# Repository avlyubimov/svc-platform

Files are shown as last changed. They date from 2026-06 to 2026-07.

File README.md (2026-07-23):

# SVC Platform — Smart Vehicle Controller

<p align="center">
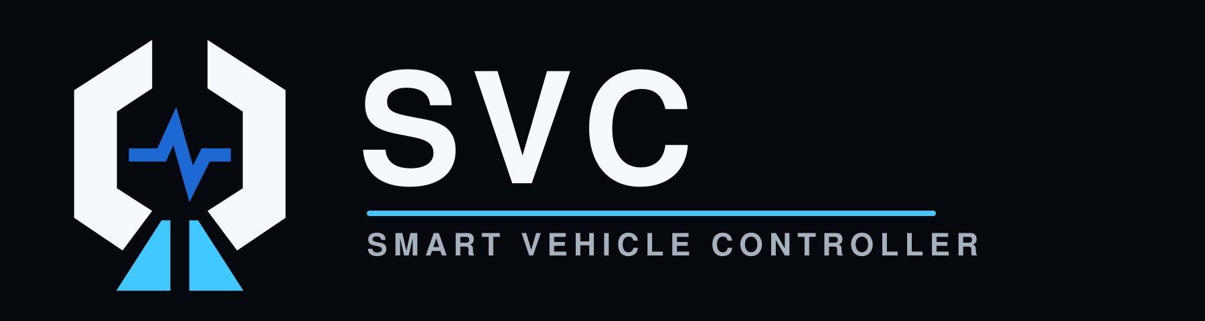
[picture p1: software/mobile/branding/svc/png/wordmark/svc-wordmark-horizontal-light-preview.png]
SVC — Smart Vehicle Controller
  
</p>

<p align="center">
  Open modular hardware, firmware, and mobile software for controlling
  auxiliary equipment on motorcycles and other vehicles.
</p>

**Reference Vehicle #001:** BMW R1200GS K25 2007<br>
**VIN:** WB10307A97ZU65028

## Mission

SVC should allow new functionality to be added primarily through configuration,
plugins, firmware updates, or Logic Board replacement without redesigning the
Power Board.

## Current status

Architecture v1.0 is frozen. Firmware safety, configuration, role mapping,
rule execution, CAN safety, update policy, and PWM ownership have host-tested
scaffolds.

The three boards are moving through the controlled EVT lifecycle independently:

| Board | Current repository state | Release boundary |
| --- | --- | --- |
| **PB-100** | `EVT-LAYOUT-AUTHORIZED` | Partial layout only; fabrication and production remain blocked |
| **LB-100** | `EVT-FAB-AUTHORIZED` | One segregated five-piece bare-PCB EVT package only |
| **FB-100** | `EVT-LAYOUT-AUTHORIZED` | Layout may continue; fabrication and production remain blocked |

These states describe the current `master` baseline. They do not authorize a
combined board order or production release. Detailed and machine-checked gates
are tracked in
[`docs/product/final-readiness.md`](docs/product/final-readiness.md).

## Mobile application

<p align="center">
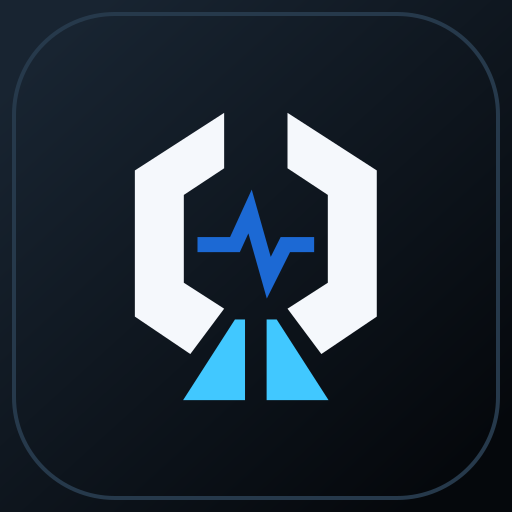
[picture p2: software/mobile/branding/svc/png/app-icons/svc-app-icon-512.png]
SVC mobile application icon
  
  &nbsp;&nbsp;&nbsp;&nbsp;
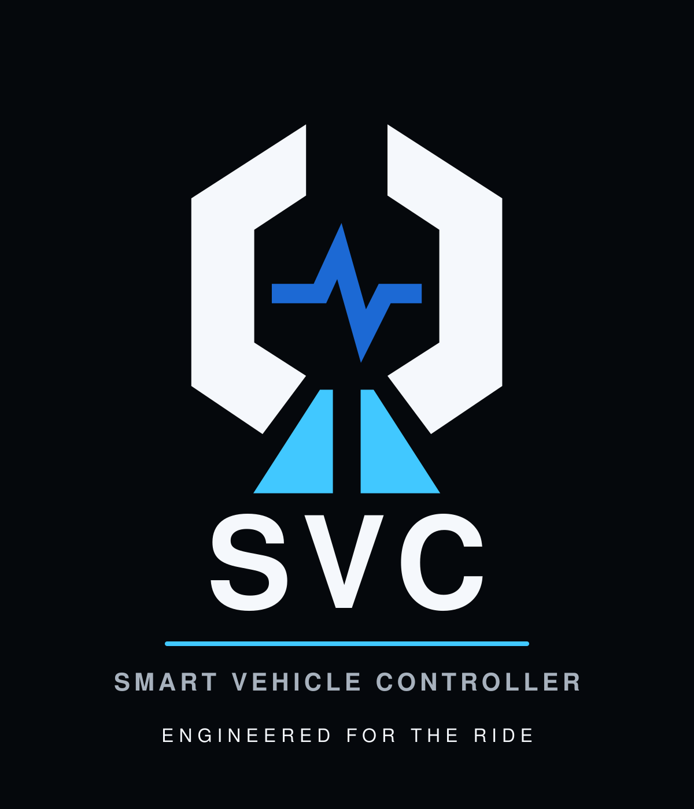
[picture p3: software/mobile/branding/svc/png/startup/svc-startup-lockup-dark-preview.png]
SVC mobile startup identity
  
</p>

SVC Mobile is being developed for iOS and Android. It provides the foundation
for live telemetry, diagnostics, vehicle data, channel control, event history,
configuration, and phone-mediated firmware updates. CHIGEE AIO-6 is treated as
a CarPlay/Android Auto projection host; the applications run on the phone.

The committed mobile baseline includes SwiftUI and Jetpack Compose
applications, BLE and protocol layers, mock data, projection scaffolds, a
GitHub Releases client, and signed-update validation. Physical channel control,
live BLE integration, and firmware transfer/installation remain disabled or
mock-backed until hardware validation closes the applicable safety gates.

The images above use only the project-owned SVC identity.
Vehicle-manufacturer artwork is not part of this repository presentation.

### SVC Ride Dashboard

<p align="center">
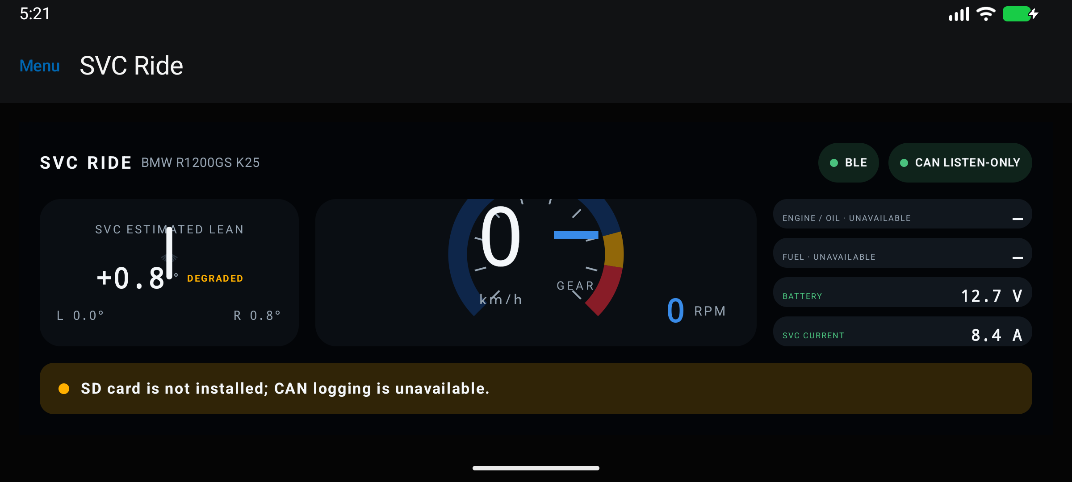
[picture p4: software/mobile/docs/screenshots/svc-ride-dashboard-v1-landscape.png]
SVC Ride Dashboard v1 with mock telemetry and SVC-only visual identity
  
</p>

Dashboard v1 is implemented for the SwiftUI and Jetpack Compose phone targets.
It uses separate versioned vehicle-performance profiles, explicit telemetry
quality states, profile-driven tachometer zones, SVC-estimated lean, Day/Night
themes, Reduce Motion, and adaptive landscape/portrait layouts. Missing CAN
signals remain `—`; gear is not inferred from speed and RPM. CarPlay and
Android Auto retain a separate, reduced information-only template.

- [Mobile overview and local build commands](software/mobile/README.md)
- [iOS application](software/mobile/ios/SVCMobile/README.md)
- [Android application](software/mobile/android/README.md)
- [Firmware update trust boundary](docs/architecture/firmware-update.md)
- [SVC identity assets](software/mobile/branding/svc/README.md)
- [Ride Dashboard implementation boundary](software/mobile/docs/ride-dashboard-roadmap.md)

## Validation

```bash
make check
```

This runs repository readiness checks, KiCad validation, firmware configuration
validation and host tests, mobile protocol tests, and release-policy checks.
The same command runs in GitHub Actions on push and pull request.

Platform-specific mobile workflows additionally build and test the Android and
iOS projects in GitHub Actions.

## Repository structure

```text
docs/                 Architecture, ADR, requirements, production docs
hardware/             KiCad and mechanical files
firmware/             Embedded firmware, bootloader, plugins
software/             SVC Studio and SVC Mobile
can-db/               Vehicle CAN databases
production/           BOM, Gerber, Pick&Place, assembly docs
tools/                Readiness, protocol, security, and release validation
```

## Board naming

- **PB-100** — Power Board, intended to remain stable for 10–15 years.
- **LB-100** — Logic Board, replaceable and upgradeable.
- **FB-100** — Front Panel Board, service interface and indicators.

## Hard rule

**Power Board is sacred.**

New features should not require Power Board redesign unless all configuration,
plugin, firmware, and Logic Board options are exhausted.

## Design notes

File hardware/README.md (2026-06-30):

# Hardware

## Boards

- PB-100 Power Board
- LB-100 Logic Board
- FB-100 Front Panel Board

Do not create KiCad layout until architecture is frozen.

Architecture v1.0 is frozen. PB-100 schematic planning may proceed, but PCB
layout remains blocked until schematic inputs are reviewed.

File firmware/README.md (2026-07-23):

# Firmware

Target architecture:
- FreeRTOS
- drivers
- event bus
- services
- plugins
- rule engine
- logger
- BLE/USB API

Update scaffolds:

- `radio/e73/` — Zephyr/nRF52840, MCUboot, MCUmgr/SMP over BLE, UART bridge,
  SWD recovery instructions.
- `bootloader/stm32h5/` — host-buildable OEMiRoT integration boundary for
  STM32H563; it is not an ad-hoc production bootloader.
- `update/` — target-neutral chunk/resume/admission/trial-boot state machine and
  the E73-to-STM32 UART framing contract.

No direct feature-to-hardware coupling. Use Output Manager and role mapping.

## Host validation

Run from `firmware/`:

```bash
make test
```

The firmware Makefile treats `core/*.h` and `services/*.h` as host-test
prerequisites, so interface changes force test binary rebuilds.

Current host tests cover:

- Configuration validation for battery settings, power budget, and output role
  enum bounds without role-to-output assumptions.
- Configuration Store record validation and two-slot selection so firmware
  defaults do not overwrite valid persisted user configuration.
- Configuration Store wrap-aware sequence selection across two persisted slots.
- Configuration Store reserved-field validation before accepting persisted
  records.
- Configuration Update preparation that refuses to persist a config until it is
  accepted against hardware capability.
- Configuration acceptance for a discovered hardware capability contract before
  startup uses a configuration.
- Hardware capability validation that checks generic board limits, safe defaults,
  CAN1 read-only policy, and config electrical limits without role assumptions.
  PB-100's compiled capability constant is checked against the JSON hardware
  capability manifest by repository validation.
- PB-100 board-level power budget service and configured load-shed ordering.
- Output Manager safe default-off, enable/disable, budget denial, telemetry
  denial, priority shedding, PWM increase revalidation, thermal derating, and
  fault lockout behavior.
- Overflow-safe projected-current denial for output starts and PWM increases.
- Battery protection warning, overflow-safe delayed cutoff latch using
  `shutdown_delay_s`, recovery, and invalid telemetry behavior.
- Event Bus FIFO order, overflow rejection, and empty-pop behavior.
- Event Dispatcher output overcurrent/fault handling through Output Manager.
- Event Log fixed-size diagnostic ring buffer with overwrite/drop accounting
  that saturates instead of wrapping the diagnostic drop counter.
- CAN1 listen-only TX denial and CAN2 expansion TX allowance.
- CAN RX Log fixed-size receive-only diagnostics plus a separate ISR-to-logger
  CAN1 queue, 44-byte v2 CRC records with 64-bit microsecond timestamps,
  identity-bearing 128-byte FatFs session headers, independent sync/close,
  restart/reopen, preallocation, rotation and torn-tail recovery. The target
  STM32 disk-I/O binding remains required before motorcycle logging tests.
- CAN Event Decode from received frames to internal Event Bus state-change
  events without output control.
- CAN Event Decode dropped-edge retry behavior when the Event Bus is full.
- Rule Event Bridge that drains CAN-derived and other condition events into rule
  condition state while retaining non-rule events for safety dispatch.
- Rule Runtime step that runs bridge, fault dispatch, and ordered rule
  evaluation in a safety-preserving order.
- System Safety Coordinator integration between battery cutoff, power-budget
  shedding, thermal derating/cutoff, Event Bus, and Output Manager output
  shutdown.
- System Safety runtime fail-safe shutdown when total-current telemetry is stale
  or invalid.
- System Safety retry of dropped runtime power-budget shed events.
- Role Resolver and Rule Engine role-action runner through Output Manager.
- Rule condition state tracking for engine, high-beam, left-indicator, and
  ambient-light day/dusk/night events.
- Rule runner evaluation for matched/unmatched conditions before role actions.
- Rule set runner for ordered multi-rule evaluation, skipped-rule accounting,
  and stop-on-first-failure behavior.
- Rule text parser for the initial supported JSON rule condition/action grammar.
- Output Manager PWM duty-cycle ownership and `pwm_allowed` enforcement.
- Rule text compile helpers from condition/action strings to in-memory
  `svc_rule_t` and ordered `svc_rule_t` arrays for multi-action rules.
- Rule-set compilation rejects invalid multi-action rule text before writing
  compiled rule entries or caller-provided condition buffers.
- Rule action grammar alignment between the JSON Schema, repository
  configuration validator, and firmware parser for supported roles and PWM
  values, with canonical `0` or `1..100` PWM literals.
- Runtime Boot path from direct configuration or persistent store that keeps
  outputs off unless configuration and hardware capability checks pass.
- Runtime Boot invalid-argument handling that leaves runtime state safe/off.
- Telemetry Snapshot validity/staleness for battery, total current, and
  per-output current samples.
- Telemetry-backed System Safety and Rule Engine wrappers for stale-data fail
  safe behavior.
- Thermal Protection allow/derate/cutoff decisions for PB-100 thermal zones.
- Thermal System Safety derating through Output Manager at warning threshold and
  shutdown through Output Manager on cutoff/stale telemetry.
- Firmware-update protocol mismatch, hardware mismatch, corrupt/repeated chunks,
  interruption/resume, incomplete file, hash/signature denial, parked-state
  admission, power loss before confirmation, rollback, and E73/STM32 version
  compatibility.

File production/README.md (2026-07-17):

# Production

This folder contains production artifacts:

- BOM drafts in `production/bom/factory_bom_draft.csv` and
  `production/bom/garage_bom_draft.csv`.
- Symbol-to-BOM ownership in `production/bom/pb100_symbol_bom_map.csv`.
- Assembly sourcing recheck tracking in
  `production/bom/pb100_assembly_sourcing_recheck.csv`.
- Current sourcing evidence snapshots in
  `production/bom/pb100_sourcing_evidence_snapshot.csv`.
- Future Gerber, Pick&Place, assembly notes, and JLCPCB/PCBWay settings after
  schematic freeze and layout authorization.

Use `make pb100-release-status` from the repository root before any PB-100 board
order discussion. It reports the schematic-freeze state, active board-release
blockers, KiCad PCB presence, and manufacturing output presence. Use
`make pb100-release-gate` when a failing shell status is required for a release
job.

Do not treat Excel as source of truth. CSV/Markdown files are the source; Excel is generated for convenience.

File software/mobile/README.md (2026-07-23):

# SVC Mobile

SVC Mobile runs on the phone. CHIGEE AIO-6 is a CarPlay/Android Auto projection
host, not an installation target.

## Layout

```text
protocol/   Versioned JSON and BLE contracts
vehicle-profiles/ Shared technical dashboard profiles
ios/        SwiftUI/CoreBluetooth application scaffold
android/    Kotlin/Compose/Android BLE/Car App scaffold
mock-data/  Hardware-free application data
```

Both phone applications start with `MockDeviceRepository`. No mobile or
projected-display action controls a physical power channel.

Vehicle performance configuration is separate from visual branding. The shared
`vehicle-profiles/vehicle-profile-index-v1.json` catalog contains confirmed
dashboard scales and reference values; unknown values remain explicit `null`.
The Generic Motorcycle fallback intentionally defines no red zone or engine
limits.

## SVC Ride Dashboard v1

The phone targets contain the same adaptive dashboard contract in SwiftUI and
Jetpack Compose. Landscape is primary; portrait rearranges the same information
without changing its meaning. The dashboard provides:

- central speed and explicit gear presentation (`N`, `1`–`6`, `BETWEEN`, `—`);
- profile-driven tachometer scale, warning/red zones, 80 rpm color hysteresis,
  smooth arc motion, and an unsmoothed numeric RPM value;
- SVC-estimated lean angle with left/right trip maxima and stationary-only
  reset;
- engine temperature, fuel, battery voltage, total SVC current, BLE/CAN state,
  and the highest-priority active warning;
- separate `SVC Day`, `SVC Night`, and ambient-light `Automatic` themes with
  configurable 250/650 lux hysteresis defaults;
- system Reduce Motion support and shared 180/300 ms motion tokens.

Every value passes through `valid`, `stale`, `degraded`, `invalid`, or
`unavailable` presentation state. Stale, invalid, and unavailable measurements
render as `—`, never as zero. The current telemetry v1 contract has no gear
measurement, so normal mock operation intentionally renders `GEAR —`. Lean is
marked degraded until mounting calibration exists; calibration remains disabled
outside the future Demo Mode.

<p align="center">
  SVC Ride Dashboard v1 using mock telemetry and only SVC visual identity
</p>

The screenshot contains no vehicle-manufacturer artwork. Full graphics are
phone-only. The experimental CarPlay/Android Auto templates expose only speed,
gear, battery, SVC current, main warning, and connection state and currently
render unavailable values rather than invented telemetry.

## Startup and personal branding

The phone apps load the common profile catalog from
`branding/brand-pack-index-v1.json` and the 2100 ms startup contract from
`branding/startup-animation-v1.json` at runtime. Manufacturer metadata and
artwork resolve from `branding/vehicle-brands/vehicle-brands-v1.json` by stable
`brandId`; `brandId`, `model`, `generation`, and `year` remain separate profile
fields. Brand text, color, asset paths, profile choices, and phase timing are
not duplicated in Swift or Kotlin.

The default personal profile is `bmw-r1200gs-k25-personal` with theme
`svc-boxer-blue`. Its preferred asset is the period-correct
`brands/bmw/bmw-roundel-1997-2020.svg`. Other profiles use
`logo-on-dark.svg` on the standard dark startup surface. Manufacturer
wordmarks are optional and fall back to the catalog display name as text. If a
profile or required logo is unavailable, the apps show the committed SVC mark,
`SMART VEHICLE CONTROLLER`, and `ENGINEERED FOR THE RIDE`. No brand artwork is
downloaded at runtime. Preview the result from
`Settings → Appearance → Preview Startup Animation`.

The public application identity is always SVC. The phone launcher, App
Store/Google Play package, CarPlay, and Android Auto use the committed SVC app
icon sourced from `branding/svc/svg/svc-app-icon.svg` and its platform exports.
Manufacturer assets appear only inside the selected post-launch phone profile
animation. The OS launch surface stays neutral black and never presents BMW
branding.

The vehicle catalog preserves `THIRD_PARTY_NOTICES.md`, its pinned Simple Icons
license/disclaimer, per-brand source URLs, and the original/derived SVG
variants. Run protocol validation after adding a brand; it requires every
catalog entry to contain `brand.json`, `logo-source.svg`, `logo-on-dark.svg`,
`logo-on-light.svg`, and `logo-accent.svg`, and parses every SVG as XML.

Profile/theme loading, mock BLE restoration, telemetry refresh, and screen
restoration start in parallel. The animation never waits for BLE; Dashboard
shows `Connecting to SVC` until restoration completes. Critical warnings use a
500 ms startup and render as a red card after it. Reduced motion also uses a
500 ms fade, while disabled animation enters the selected screen immediately.
No POST statuses or fabricated `OK` values appear in startup.

The animation is phone-only. CarPlay and Android Auto retain host-controlled
launch transitions and show only the SVC app identity, profile name, permitted
accent, and informational templates.

Future Dashboard Demo Mode, telemetry protocol v2, real BLE telemetry, and
verified BMW K25 CAN signals are intentionally separate changes. See
[`docs/ride-dashboard-roadmap.md`](docs/ride-dashboard-roadmap.md).

## GitHub Releases client

The iOS and Android data layers include an unauthenticated client for this
public repository. No PAT is stored or sent:

- stable uses `GET /repos/avlyubimov/svc-platform/releases/latest`;
- beta and test load the public release list and select matching prerelease
  tags;
- tags must be `svc-vX.Y.Z`, `svc-vX.Y.Z-beta.N`, or
  `svc-vX.Y.Z-test.N`;
- `firmware-manifest.json`, component assets, and detached signature assets
  are downloaded over HTTPS;
- GitHub asset size/digest, manifest size/SHA-256, detached-signature
  size/SHA-256, key ID, and RSA-PSS/SHA-256 signature are checked before a
  manifest is accepted.

The production public key is injected into each phone build after production
key provisioning; private keys never enter a mobile build. Missing or
unrecognized public-key material fails closed. Installation and BLE firmware
transfer remain mock-only. `review-raw` assets are explicitly non-installable.

## Protocol validation

```bash
python3 -m pip install -r tools/mobile_protocol_validation/requirements.txt
python3 tools/validate_mobile_protocol.py
python3 tools/validate_ota_release.py scaffold
PYTHONPATH=tools python3 -m unittest discover \
  -s tools/mobile_protocol_validation/tests
```

## iOS

Requirements: current Xcode and XcodeGen.

```bash
cd software/mobile/ios/SVCMobile
xcodegen generate
xcodebuild \
  -project SVCMobile.xcodeproj \
  -scheme SVCMobile \
  -sdk iphonesimulator \
  -destination 'platform=iOS Simulator,name=iPhone 16' \
  test
```

The default target has no CarPlay entitlement. See
`ios/SVCMobile/README.md` before enabling the experimental scene.

## Android

Requirements: JDK 21, Android SDK 36, and Gradle 8.11.1.

```bash
gradle -p software/mobile/android \
  :app-mobile:assembleDebug \
  test
```

Install `app-mobile/build/outputs/apk/debug/app-mobile-debug.apk`, enable Android
Auto developer mode and unknown sources, then start Desktop Head Unit according
to Google's DHU instructions. The merged APK contains the experimental IoT
`CarAppService`.

## Mock data

`mock-data/device-v1.json` intentionally marks undecoded CAN values unavailable.
Mock values are development data and are never substituted for missing vehicle
signals on a real connection.

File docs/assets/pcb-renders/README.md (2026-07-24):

# Rev.1 EVT PCB Renders

These KiCad renders document the current board states. They are review aids;
release authority remains in the board-specific checklists. LB-100 alone is
`EVT-FAB-AUTHORIZED` for five bare test PCBs. No image authorizes assembly,
PB-100, motorcycle use or production.

| Board | Top | Bottom | Captured state |
|---|---|---|---|
| FB-100 | [top](FB-100-rev1-evt-top.png) | [bottom](FB-100-rev1-evt-bottom.png) | Four-layer connectivity-complete routing with stackup-derived USB pair and GND zones; fab review and supplier DFM remain open |
| LB-100 | [top](LB-100-rev1-evt-top.png), [isometric](LB-100-rev1-evt-isometric.png) | [bottom](LB-100-rev1-evt-bottom.png) | Connectivity-complete six-layer EVT board with 2,274 segments, 409 standard through vias, four GND zones, six-layer E73 keepout and zero refilled DRC errors/unconnected items |
| PB-100 | [top](PB-100-rev1-evt-top.png), [isometric](PB-100-rev1-evt-isometric.png) | [bottom](PB-100-rev1-evt-bottom.png) | Eight-layer deterministic routed baseline with 5,049 segments, 874 conventional through vias, 38 zones and 36 explicit connectivity blockers; fabrication remains blocked |

The images were generated on 2026-07-23 from the tracked `.kicad_pcb` files
with KiCad CLI 10.0.4. KiCad renders the FB-100 GND zones from the tracked zone
definitions; the tracked board is not modified only for rendering. Regenerate
the board renders from the repository root with:

```bash
mkdir -p docs/assets/pcb-renders
kicad-cli pcb render hardware/front-board/FB-100/kicad/FB-100.kicad_pcb -o docs/assets/pcb-renders/FB-100-rev1-evt-top.png --side top --width 1800 --height 1000 --background opaque --quality high
kicad-cli pcb render hardware/front-board/FB-100/kicad/FB-100.kicad_pcb -o docs/assets/pcb-renders/FB-100-rev1-evt-bottom.png --side bottom --width 1800 --height 1000 --background opaque --quality high
kicad-cli pcb render hardware/logic-board/LB-100/kicad/LB-100.kicad_pcb -o docs/assets/pcb-renders/LB-100-rev1-evt-top.png --side top --width 1800 --height 1200 --background opaque --quality high
kicad-cli pcb render hardware/logic-board/LB-100/kicad/LB-100.kicad_pcb -o docs/assets/pcb-renders/LB-100-rev1-evt-bottom.png --side bottom --width 1800 --height 1200 --background opaque --quality high
kicad-cli pcb render hardware/logic-board/LB-100/kicad/LB-100.kicad_pcb -o docs/assets/pcb-renders/LB-100-rev1-evt-isometric.png --side top --width 1800 --height 1200 --background opaque --quality high --perspective --floor --rotate 325,0,35
kicad-cli pcb render hardware/power-board/PB-100/kicad/PB-100.kicad_pcb -o docs/assets/pcb-renders/PB-100-rev1-evt-top.png --side top --width 1800 --height 1080 --background opaque --quality high
kicad-cli pcb render hardware/power-board/PB-100/kicad/PB-100.kicad_pcb -o docs/assets/pcb-renders/PB-100-rev1-evt-bottom.png --side bottom --width 1800 --height 1080 --background opaque --quality high
kicad-cli pcb render hardware/power-board/PB-100/kicad/PB-100.kicad_pcb -o docs/assets/pcb-renders/PB-100-rev1-evt-isometric.png --side top --width 1800 --height 1200 --background opaque --quality high --perspective --floor --rotate 325,0,35
```

No Gerber, drill, BOM/CPL, pick-and-place, manufacturing ZIP, or other board
order artifact is stored in this image directory. The separately controlled
LB-100 bare-PCB EVT package is under
`hardware/logic-board/LB-100/manufacturing/evt-rev1/`.

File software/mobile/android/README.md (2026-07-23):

# SVCMobile for Android

Modules:

- `app-mobile` — phone UI built with Jetpack Compose;
- `app-automotive` — projected Android Auto `CarAppService`;
- `core-model` — versioned telemetry and repository contracts;
- `core-protocol` — manifest and chunk protocol;
- `core-ble` — Android BLE API and mock transport;
- `core-update` — OTA admission and transfer state;
- `core-mock` — mock device repository.

The phone target packages the shared vehicle-brand catalog, SVC artwork, and
the ignored `software/mobile/branding/local` source for future owner-only
custom packs. Profiles resolve manufacturers by stable `brandId`, use
`logo-on-dark.svg` unless a preferred asset is declared, and fall back to the
catalog display name when no wordmark exists. Startup uses one linear
`Animatable` timeline, an always-dark surface, system animator-scale detection,
and the same 2100/500 ms timing as iOS. Appearance settings provide
profile/fallback selection and replay.

The phone Dashboard is a Jetpack Compose SVC Ride layout with landscape-first
and portrait arrangements. It loads the shared technical profile separately
from branding, maps all telemetry through explicit quality states, leaves
telemetry-v1 gear unavailable, and supports profile-driven tachometer zones,
SVC-estimated lean, Day/Night ambient-light hysteresis, and Reduce Motion.
Compose previews use SVC-only sample identity.

## Build and test

```bash
gradle :app-mobile:assembleDebug test
```

The debug phone APK contains the merged Android Auto service. Enable Android
Auto developer mode and unknown sources, install the APK, and run Google's
Desktop Head Unit. The service declares the experimental IoT category and shows
information-only templates. The template is not the graphical phone dashboard;
it contains only speed, gear, battery, SVC current, main warning, and connection
state.

Successful DHU execution does not guarantee Google Play eligibility. IoT
category fit, templated-app requirements, driver-distraction rules, and current
distribution policy require a separate review before publication.

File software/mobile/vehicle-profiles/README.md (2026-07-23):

# Vehicle performance profiles

Vehicle performance profiles are runtime configuration shared by the iOS and
Android phone applications. They are separate from `branding/`: a BrandPack
controls presentation, while a vehicle profile supplies confirmed technical
limits and dashboard scale metadata.

`vehicle-profile-index-v1.json` selects the default and safe fallback profiles.
Every listed JSON document validates against `vehicle-profile-v1.schema.json`.
Unknown values remain explicit `null`; clients must not replace them with
generic-looking numbers.

The BMW reference profile defines the SVC tachometer scale, warning zone, red
zone, idle band, fuel capacity, and ice-warning threshold approved for
Reference Vehicle #001. It intentionally leaves `revLimiterRpm` null because no
limiter value has been confirmed.

The Generic Motorcycle fallback has no warning/red zone and no assumed engine,
gearbox, fuel, or year data. A dashboard using it must render performance
features unavailable until a suitable profile is selected.

Performance profiles do not contain CAN identifiers, decoding formulas, BLE
state, theme colors, logos, or safety commands.

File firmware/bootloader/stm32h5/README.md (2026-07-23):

# STM32H563 secure-update scaffold

This directory is an integration boundary, not a replacement bootloader.
STM32H563 production work must start from ST's OEMiRoT examples for
`NUCLEO-H563ZI`/the selected STM32CubeH5 release.

The host-buildable code proves:

- transport code writes only through an injected staging-slot interface;
- a failed staging write is never acknowledged;
- sequence, offset, and CRC checks are shared with the versioned update state
  machine;
- no phone or E73 decision can bypass STM32 admission.

## Host build

```bash
cmake -S firmware/bootloader/stm32h5 \
  -B build/stm32-update
cmake --build build/stm32-update
ctest --test-dir build/stm32-update --output-on-failure
```

This does not produce a deployable STM32 image. Target output remains blocked on
the accepted CubeH5 version, final flash layout, OEMiRoT provisioning, option
bytes, HAL/storage integration, watchdog integration, and production key
handling.

E73 forwards a candidate through the UART protocol in
`firmware/update/uart-update-v1.md`. STM32 writes and validates its own download
slot. A damaged STM32 boot chain is recovered through SWD/USB, not through E73.

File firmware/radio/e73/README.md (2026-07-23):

# E73 nRF52840 radio scaffold

Target module: E73-2G4M08S1C (nRF52840).

The current compile-validation board is `nrf52840dk/nrf52840`. It proves Zephyr,
Bluetooth, MCUmgr, MCUboot, telemetry stub, update state machine, and UART source
compatibility only. It is not the final LB-100 board definition or pin map.

## Build

With a Zephyr 4.2 workspace:

```bash
west build \
  --sysbuild \
  -b nrf52840dk/nrf52840 \
  firmware/radio/e73
```

Sysbuild enables MCUboot. The upstream MCUboot development key path is acceptable
only for compile validation and must be treated as
`TEST KEY — NOT FOR PRODUCTION`. Production signing material is not stored in
the repository.

## Included boundary

- BLE peripheral with LE Security Mode 1 level 2 request;
- MCUmgr/SMP over BLE and image management;
- MCUboot primary/secondary test-boot direction;
- explicit MCUboot test request and post-health-check image confirmation;
- BLE-to-UART bridge abstraction;
- unavailable-by-default telemetry stub;
- shared resumable update state machine.

The selected console UART is only a compile placeholder. Final E73 UART pins,
flow control, baud rate, wake behavior, BLE security provisioning, GATT
authorization, flash partitions, and radio power behavior require the accepted
LB-100 board definition and EVT measurements.

## First programming and recovery through SWD

LB-100 exposes E73 `SWDIO`, `SWDCLK`, `BLE_RESET_N`,
`RADIO_SENSOR_3V3` target reference, and GND on accessible pads.

1. Keep PB outputs disabled and power LB-100 from the approved current-limited
   service source.
2. Connect the probe target-reference input to `RADIO_SENSOR_3V3`; do not drive
   or source that rail from the probe.
3. Connect GND, SWDIO, SWDCLK, and optional reset.
4. Verify target voltage before any erase/program command.
5. Program MCUboot and the signed development application.
6. Read back/verify, reset, and capture the first boot log.
7. Confirm image slots and mark the known-good development image confirmed.

Do not drive E73 signals when the radio rail is off. BLE DFU is a field-update
path, not a replacement for SWD first programming or hardware recovery.

## MCUmgr evidence

- https://docs.zephyrproject.org/latest/services/device_mgmt/mcumgr.html
- https://docs.zephyrproject.org/latest/services/device_mgmt/smp_transport.html
- https://docs.zephyrproject.org/latest/services/device_mgmt/ota.html

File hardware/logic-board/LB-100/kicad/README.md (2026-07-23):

# LB-100 KiCad Project

Status: `EVT-FAB-AUTHORIZED`; connectivity-complete six-layer Rev.1 EVT layout

This directory contains the reviewed value-bearing LB-100 schematic,
project-local libraries and deterministically generated PCB.

The controlled `LB-100.kicad_pcb` contains all 104 schematic footprints, eight mounting
holes, the 100 mm x 70 mm outline, 2,274 routed segments, 409 standard
0.50/0.30 mm through vias and four GND zones. KiCad 10.0.4 refill DRC reports
zero errors and zero unconnected items; parity contains only H1-H8. Five
non-assembly pads provide E73 SWDIO, SWDCLK, reset, switched target reference
and GND recovery access.

The six-layer stack model is JLCPCB `JLC06161H-3313`. In2.Cu and In4.Cu are
solid GND reference planes, In1.Cu and In3.Cu carry signals, and the E73 rule
area covers every copper layer. The routing manifest is the source for board
generation; do not hand-edit generated copper.

Validation with KiCad 10.0.4:

```sh
python3 tools/validate_lb100_layout.py
```

The validator checks deterministic generation, schematic parity, route/via
counts, standard through-via construction, reference-plane exclusivity, USB
geometry and analytical impedance regression, VEML7700 disposition, the
six-layer E73 keepout and the exact reviewed non-electrical warning set.

Any EVT fabrication package must remain LB-only, marked
`LB-100 REV.1 EVT - NOT FOR PRODUCTION`, and must pass the supplier stackup,
impedance and DFM preflight before payment. PB-100 and the combined three-board
order remain `NO-GO`. Authorized LB manufacturing outputs are segregated under
`../manufacturing/evt-rev1/`; no assembly outputs are authorized.

## Source documents

- `../LB-100-layout-progress.md`
- `../LB-100-evt-fab-review-2026-07-22.md`
- `../LB-100-e73-antenna-keepout.md`
- `../LB-100-pcb-layout-start-checklist.csv`
- `../../../../production/board-order/three_board_layout_rules.md`
- `../../../../docs/adr/ADR-0014-lb-fb-baseline-requirements.md`

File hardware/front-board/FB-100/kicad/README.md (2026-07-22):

# FB-100 KiCad Project

Status: `EVT-LAYOUT-AUTHORIZED`; connectivity routing complete; fab review open

This directory contains the reviewed value-bearing FB-100 KiCad schematic and
project-local symbol/footprint libraries.

The controlled `FB-100.kicad_pcb` placement and routing are generated from the frozen
44-component schematic and project-local footprints. Mechanical-envelope and
USB/no-back-power inputs are applied. The route manifest contains 457 segments,
48 vias and four filled GND zones with zero refilled DRC or unconnected findings.
USB stack geometry, analytical impedance/skew and transition return-via checks
are automated. Supplier field-solver confirmation, physical JFB1 cable/latch
fit, enclosure integration and final assembly DFM remain open. There are no
manufacturing outputs: Gerbers, drills, pick-place files, BOM/CPL order
packages, zipped fabrication packages, and board orders remain blocked until
the later prototype/production gates close.

Release boundary: no manufacturing outputs are authorized.

## Source Documents

- `../FB-100-requirements.md`
- `../FB-100-schematic-freeze-checklist.md`
- `../FB-100-pcb-layout-start-checklist.csv`
- `../FB-100-footprint-binding-inventory.csv`
- `../FB-100-footprint-binding-closeout.csv`
- `../FB-100-footprint-binding-closeout.md`
- `../FB-100-mechanical-envelope-inventory.csv`
- `../FB-100-mechanical-layout-inputs.csv`
- `../FB-100-usb-no-back-power-layout-rules.csv`
- `../FB-100-board-release-blocker-register.csv`
- `../../../../production/board-order/three_board_footprint_binding_status.csv`
- `../../../../production/board-order/three_board_mechanical_envelope_status.csv`
- `../../../logic-board/LB-100/LB-100-requirements.md`
- `../../../../docs/adr/ADR-0014-lb-fb-baseline-requirements.md`

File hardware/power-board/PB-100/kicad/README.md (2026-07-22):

# PB-100 KiCad Project

Status: `EVT-LAYOUT-AUTHORIZED`; board import may begin; fabrication blocked

This directory contains the preliminary KiCad project for PB-100.

## Current boundary

- `PB-100.kicad_pro`: project metadata scaffold.
- `PB-100.kicad_sch`: top-level schematic note sheet with linked child sheets.
- `sheets/*.kicad_sch`: preliminary child schematic capture sheets with
  role-agnostic `OUT1`..`OUT10` nets, CAN1 DNP/open notes, and ERC-clean
  abstract class instances.
- `sym-lib-table`: project-local symbol library table.
- `fp-lib-table`: project-local footprint library table.
- `lib/PB100.kicad_sym`: preliminary abstract block symbols, first
  project-local concrete MPN symbols, and non-final class symbols for passive
  or garage-installed schematic elements.
- `lib/PB100.pretty/`: empty preliminary local footprint library.

The controlled `PB-100.kicad_pcb` is now a partial board-import milestone. It
places all 28 schematic components that currently have reviewed Footprint
properties, the eight mechanical holes, functional zones and the 150 mm x
90 mm outline. It intentionally reports 46 missing footprints and six U1
unconnected-pin parity findings because the preliminary schematic has not yet
promoted every power-stage passive, terminal and exact package. It contains no
routing or copper pours and cannot enter fabrication review in this state.

ADR-0019 and ADR-0020 permit controlled board import, placement, routing,
copper pours and extraction while the final EVT schematic review remains open.
There are no manufacturing outputs; Gerber, drill, pick-and-place, BOM/CPL and
zipped manufacturing outputs remain blocked until
`EVT-FAB-AUTHORIZED` after DRC, parity, 40 A electrothermal/clamp-loop review,
DFM, connector fit and laboratory safety review.

## Source documents

- `../PB-100-schematic-capture-plan.md`
- `../PB-100-schematic-capture-work-queue.csv`
- `../PB-100-review-release-manifest.csv`
- `../PB-100-schematic-readiness-dashboard.csv`
- `../PB-100-net-naming.md`
- `../PB-100-schematic-instance-plan.csv`
- `../PB-100-schematic-instance-symbol-map.csv`
- `../PB-100-schematic-sheet-reference-map.csv`
- `../PB-100-schematic-net-domain-plan.csv`
- `../PB-100-output-channel-pin-contract.csv`
- `../PB-100-output-controller-pin-template.csv`
- `../PB-100-output-net-expansion.csv`
- `../PB-100-output-stage-design-values.csv`
- `../PB-100-input-controller-pin-template.csv`
- `../PB-100-input-protection-pin-contract.csv`
- `../PB-100-input-power-design-values.csv`
- `../PB-100-current-monitor-pin-template.csv`
- `../PB-100-logic-buck-pin-template.csv`
- `../PB-100-logic-power-design-placeholders.csv`
- `../PB-100-logic-power-design-values.csv`
- `../PB-100-kicad-prep.md`
- `../PB-100-kicad-sheet-manifest.csv`
- `../PB-100-kicad-footprint-plan.csv`
- `../PB-100-footprint-binding-inventory.csv`
- `../PB-100-symbol-mpn-readiness.csv`
- `../PB-100-symbol-capture-worklist.csv`
- `../PB-100-symbol-pin-evidence.csv`
- `../PB-100-symbol-open-items.md`
- `../PB-100-schematic-freeze-checklist.md`
- `../PB-100-pcb-layout-start-checklist.csv`
- `../PB-100-mechanical-envelope-inventory.csv`
- `../PB-100-schematic-freeze-gap-register.csv`
- `../PB-100-validation-traceability.csv`
- `../PB-100-test-point-plan.csv`
- `../PB-100-fault-response-matrix.csv`
- `../PB-100-can1-safety-verification.csv`
- `../../../../production/bom/pb100_assembly_sourcing_recheck.csv`
- `../../../../production/bom/pb100_sourcing_evidence_snapshot.csv`
- `../../../../production/board-order/three_board_footprint_binding_status.csv`
- `../../../../production/board-order/three_board_mechanical_envelope_status.csv`
- `../../../../firmware/configs/hardware/pb-100-capabilities.json`

## Next KiCad work

1. Review `../PB-100-pcb-layout-start-checklist.csv`, ADR-0019 and
   `../PB-100-evt-prototype-plan.md`.
2. Open `PB-100.kicad_pro` in KiCad.
3. Let KiCad normalize project settings if needed.
4. Review linked child schematic sheets listed in
   `PB-100-schematic-capture-plan.md` against the trace and freeze-review
   artifacts.
5. Review preliminary concrete MPN symbols against the official data sheets
   listed in `PB-100-symbol-capture-worklist.csv`.
6. Replace abstract class instances with final electrical symbols, values, and
   footprints only after package drawings, pinouts, SOA, and sourcing gates are
   checked.
7. Continue the controlled `PB-100.kicad_pcb` import by promoting the missing
   output-stage passives, terminals, test points, DNP alternative sites,
   replaceable gate elements, isolation links, safe-off provisions and EVT
   serial field before routing is declared complete.
8. Do not create Gerbers, drills, pick-place, BOM/CPL, manufacturing ZIP files,
   fabrication packages or PCBA orders until `EVT-FAB-AUTHORIZED`.

## Validation

Run from repository root:

```bash
python3 tools/validate_pb100.py
python3 tools/validate_pb100_layout.py
```

The validator intentionally fails if manufacturing artifacts appear before
layout review and order evidence close.

The validator requires `kicad-cli` version `10.0.4`. It fails if KiCad is
missing or a different version is installed.

The validator also rejects `sheet-placeholder`/`Placeholder sheet` markers,
runs schematic ERC, requires zero reported violations, exports a temporary KiCad
S-expression netlist, checks that all child sheets in
`PB-100-kicad-sheet-manifest.csv` are linked from the top-level schematic, and
requires at least 20 schematic components plus 20 electrical nets in the exported
netlist. Empty child sheets are therefore not allowed to pass CI.

The current child sheets use passive preliminary class-symbol pins so ERC checks
hierarchy, net continuity, and capture completeness without treating abstract
planning symbols as final electrical models. Schematic freeze must replace those
abstract instances with reviewed final pin electrical types, values, footprints,
and MPN selections.

KiCad schematic and symbol files are also checked for accessory-role tokens such
as `FOG`, `USB`, `SEAT`, `CHIGEE`, `DVR`, and `BRAKE`. PB-100 output artifacts
must use generic `OUT1`..`OUT10` naming only. The protected manual-request inputs
`FOG_A_SW_IN` and `FOG_B_SW_IN` are the only explicit exceptions; they do not
assign roles to outputs and cannot bypass Output Manager authorization.

Rows in `PB-100-symbol-capture-worklist.csv` that say `preliminary symbol
created` are checked against `lib/PB100.kicad_sym`; those symbols must stay
excluded from BOM and board output until schematic freeze.

`PB-100-symbol-pin-evidence.csv` records the official data-sheet pin tables used
for concrete MPN symbols and the internal schematic-class pin contracts used for
non-final class symbols. Validation checks each recorded pin number/name against
the KiCad symbol library.

`PB100_JPB1_100PIN_PRELIM` is generated from
`PB-100-b2b-pin-map.csv`; validation checks all 100 connector pin names and
numbers directly against that map.

The readiness dashboard and pin/value contract CSVs are checked against the
instance map, JPB1 pin map, net-domain plan, and freeze policy. Layout-start
work is now controlled by `../PB-100-pcb-layout-start-checklist.csv`.

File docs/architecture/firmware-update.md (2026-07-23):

# Firmware Update Architecture

## Trust boundary

GitHub and the phone transport release artifacts; they are not the root of
device trust. Each target verifies its own candidate before installation.

```text
GitHub Release (future, after target signing is ready)
  firmware-manifest.json
  E73 MCUboot-signed image
  STM32 OEMiRoT-signed image
  detached release signatures
            |
            | HTTPS, manifest/hash checks
            v
phone cache
            |
            | authenticated BLE, resumable chunks
            v
E73 staging / MCUboot secondary slot
            |
            +-- E73 image: MCUboot test boot -> confirm / rollback
            |
            +-- STM32 image: framed UART -> STM32 download slot
                                      -> OEMiRoT verify/install
                                      -> test boot -> confirm / rollback
```

## Release manifest

`firmware-manifest.json` is versioned independently from BLE protocol version.
Every component identifies:

- target and semantic version;
- compatible hardware revisions;
- required protocol version;
- file name and byte length;
- SHA-256 digest;
- native image format (`mcuboot-signed`, `oemirot-signed`, or
  non-installable `review-raw`);
- detached release-signature asset, size, SHA-256, algorithm, and key ID;
- minimum bootloader version.

The mobile parser rejects unknown schema versions, duplicate targets, path-like
filenames, incompatible hardware, protocol mismatch, invalid size, wrong digest,
invalid signature, an image that claims installability without the required
native target format, or an insufficient bootloader. Dev fixtures may use
explicit placeholder digests. Release validation rejects every placeholder.

Production signing keys are never generated or stored in this repository.

## Release workflow scaffold

`.github/workflows/firmware-release.yml` is currently review-only. It never
creates a GitHub Release and emits components with `installable=false` and
`imageFormat=review-raw`. The allowlisted
`.github/workflows/firmware-candidates.yml` producer remains intentionally
absent until the E73 target build and STM32 OEMiRoT build produce genuine
target images.

Before signing, the workflow validates strict channel-specific SemVer and tag
mapping:

- stable: `0.1.0` -> `svc-v0.1.0`;
- beta: `0.1.0-beta.1` -> `svc-v0.1.0-beta.1`;
- dev/test: `0.1.0-test.1` -> `svc-v0.1.0-test.1`.

The candidate run must be a successful same-repository run of the allowlisted
workflow, must not originate from a fork, and its commit must be reachable from
`master`. Both candidate files require GitHub artifact attestations tied to
that workflow and source commit.

The `sign-review` job uses the protected `firmware-production` environment.
Only its signing step receives `OTA_PROD_SIGNING_KEY_B64` and
`OTA_PROD_SIGNING_KEY_PASSWORD`. The encrypted RSA private key stays outside
the repository. `OTA_PROD_PUBLIC_KEY_SHA256` is a non-secret protected
environment variable used to pin the derived public-key identity. Signing uses
detached RSA-PSS/SHA-256 signatures and immediately verifies each signature
with the derived public key before packaging.

The workflow grants no top-level token permissions. Candidate validation gets
only `actions: read`, `attestations: read`, and `contents: read`; protected
review signing adds only `id-token: write` and `attestations: write`. The
signing job is hard-blocked unless `github.ref == 'refs/heads/master'`.
Repository settings must keep
`firmware-production` on a custom deployment-branch policy that allows only
`master`.

Detached release signatures do not replace native target signing:

- E73 installability requires an MCUboot-signed image;
- STM32 installability requires an OEMiRoT-signed image;
- a raw or host-only binary is a review payload and is never named
  `signed.bin`.

## BLE transfer

The control plane creates a transfer session and negotiates protocol version,
component, size, hash, chunk size, and resume point. Each data frame carries a
transfer ID, absolute offset, sequence number, payload length, and CRC-32.

The receiver:

- acknowledges only committed chunks;
- returns the next expected sequence and offset;
- NACKs a corrupt or out-of-order chunk;
- accepts an idempotent retry of the last committed chunk;
- persists a bounded resume record;
- resumes after a temporary BLE disconnect only after re-authentication;
- invalidates the session when metadata changes.

The complete candidate is hashed after transfer. Installation cannot begin from
a partially received file.

## E73

The E73 direction is Zephyr or Nordic nRF Connect SDK with:

- MCUboot;
- MCUmgr/SMP over BLE;
- signed images;
- primary and secondary slots;
- test boot;
- explicit image confirmation;
- rollback after failed health confirmation.

The repository build target uses `nrf52840dk/nrf52840` only as a compile
validation board until the final E73/LB-100 board definition and pin mapping are
accepted. First programming and recovery use the already routed E73 SWD pads.
BLE DFU never replaces SWD recovery.

## STM32H563

STM32H563 provides up to 2 MiB dual-bank flash. The selected implementation
direction is ST OEMiRoT for STM32H563 rather than an ad-hoc bootloader.

The immutable boot stage owns:

- image size and layout checks;
- hardware revision and dependency checks;
- SHA-256/integrity verification;
- digital-signature authentication;
- anti-rollback/minimum-version policy;
- candidate installation;
- boot-attempt accounting;
- watchdog-backed trial boot;
- explicit application confirmation;
- automatic rollback or recovery entry.

E73 is a transport peer only. STM32 receives framed UART data, writes its own
download/staging slot, verifies the final hash, and requests reboot. If the
STM32 boot chain itself is damaged, recovery remains SWD/USB.

Final flash partition sizes, OEMiRoT provisioning, option bytes, TrustZone/HDPL
policy, target keys, and CubeH5 integration require an accepted target-specific
security review before hardware programming.

## Admission checks

`install` returns a stable denial code for every failed condition:

| Code | Condition |
|---|---|
| `vehicle_moving` | speed is non-zero, invalid, or stale |
| `engine_running` | engine state is on, invalid, or stale |
| `outputs_active` | any Output Manager channel is active |
| `critical_fault` | a critical diagnostic is active |
| `battery_out_of_range` | battery sample is invalid/stale or outside configured limits |
| `temperature_out_of_range` | required board temperature is invalid/stale or outside configured limits |
| `link_unstable` | BLE/UART health is below the configured threshold |
| `file_incomplete` | committed length differs from manifest length |
| `hash_mismatch` | SHA-256 differs |
| `signature_invalid` | target verifier rejects the signature |
| `hardware_mismatch` | board revision is absent from the component allowlist |
| `protocol_incompatible` | negotiated protocol is unsupported |
| `bootloader_too_old` | minimum bootloader is not met |

The phone displays these reasons, but only the device authorizes installation.

## Failure behavior

- Power loss before a complete staged image leaves the active image unchanged.
- Power loss after install request but before confirmation boots according to
  OEMiRoT/MCUboot trial rules.
- Failure to confirm rolls back.
- A rollback never restores or rewrites user configuration.
- Dangerous commands require an authenticated confirmed session.
- CarPlay and Android Auto cannot request install.
- Review packages cannot request install or BLE transfer.

## Source evidence

- Zephyr MCUmgr:
  https://docs.zephyrproject.org/latest/services/device_mgmt/mcumgr.html
- Zephyr SMP transport:
  https://docs.zephyrproject.org/latest/services/device_mgmt/smp_transport.html
- Zephyr OTA:
  https://docs.zephyrproject.org/latest/services/device_mgmt/ota.html
- STM32H563:
  https://www.st.com/en/microcontrollers-microprocessors/stm32h563ii.html
- STM32H563 OEMiRoT:
  https://wiki.st.com/stm32mcu/wiki/Security:How_to_start_with_STM32CubeMX_OEMiRoT_Boot_path_on_STM32H563
- GitHub Releases REST API:
  https://docs.github.com/en/rest/releases/releases
- GitHub artifact attestations:
  https://docs.github.com/en/actions/concepts/security/artifact-attestations
- GitHub Actions script-injection guidance:
  https://docs.github.com/en/actions/concepts/security/script-injections

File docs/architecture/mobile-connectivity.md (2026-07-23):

# Mobile Connectivity

## Boundary

SVC Mobile is an optional client of the SVC platform. Core vehicle behavior,
rules, logging, protection, and Output Manager continue to work without a phone,
CHIGEE, GitHub, or Internet access.

```text
GitHub Releases --HTTPS--> iOS / Android phone
                                  |
                                  +--CarPlay / Android Auto--> CHIGEE AIO-6
                                  |
                                  +--authenticated BLE-------> E73 / nRF52840
                                                                    |
                                                                    +--UART--> STM32H563
```

CHIGEE AIO-6 documents wireless CarPlay/Android Auto pairing with a phone. SVC
therefore runs on that phone and supplies only a projected, template-constrained
surface to CHIGEE. Installing an SVC APK or iOS binary on CHIGEE is not part of
the platform architecture.

The phone can maintain the projected-display session and the separate SVC BLE
session at the same time. Actual coexistence, reconnect latency, RF range, and
throughput require EVT measurement with the production enclosure.

## Application layers

```text
SwiftUI / Jetpack Compose
        |
Application state and use cases
        |
DeviceRepository
        +-- MockDeviceRepository
        +-- BleDeviceRepository
                |
          versioned protocol
                |
          BLE transport
```

UI code does not own CoreBluetooth or Android BLE callbacks. Repository and
transport interfaces make mock startup and protocol tests deterministic.

## Phone application

The full phone application contains:

- discovery and pairing;
- main telemetry dashboard;
- ten generic channel states and currents;
- diagnostics and CAN telemetry;
- event log;
- device and protocol versions;
- firmware release check, transfer, and confirmed installation;
- settings and calibration.

No first-iteration phone action enables, disables, or PWM-controls a physical
output. Future output actions require an accepted command contract and still
flow through device services and Output Manager.

## CarPlay

The experimental CarPlay scene is guarded by `SVC_CARPLAY_EXPERIMENT`. The
default build has no CarPlay scene manifest and no entitlement.

If Apple approves a suitable category:

1. request the category-specific CarPlay entitlement from Apple;
2. accept the CarPlay entitlement addendum;
3. enable the managed capability for the App ID;
4. create a new provisioning profile;
5. add the approved entitlement to a non-placeholder entitlements file;
6. enable the CarPlay scene configuration and compile flag;
7. validate only system-provided templates in Simulator and on an approved host.

The projected view is information-only: battery voltage, total current, engine
temperature, speed, RPM, fuel use, ambient temperature, light, lean angle,
warnings, and generic channel states. It exposes neither OTA nor output control.

Apple supports a fixed set of CarPlay categories and reviews entitlement
requests. An arbitrary SVC instrument dashboard is not assumed to qualify.
Automatic selection of SVC after CarPlay reconnect is also not guaranteed.

## Android Auto

The experimental `CarAppService` uses AndroidX Car App Library templates and
declares `androidx.car.app.category.IOT`. It exposes status, warnings, channel
state, and principal motorcycle metrics without controls or OTA.

The library uses a host application to render client templates. IoT category
declaration and successful Desktop Head Unit execution do not guarantee Google
Play approval; supported-category, driver-distraction, quality, and distribution
rules must be reviewed again before publication.

## Source evidence

- CHIGEE AIO-6 manual:
  https://www.chigee.com/pages/manual-for-aio6-max
- Apple CarPlay:
  https://developer.apple.com/carplay/
- Apple entitlement request:
  https://developer.apple.com/documentation/carplay/requesting-carplay-entitlements
- Android for Cars App Library:
  https://developer.android.com/training/cars/apps/library

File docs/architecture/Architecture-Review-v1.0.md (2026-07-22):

# SVC Architecture Review v1.0

Status: Frozen

This review defines the v1.0 architecture baseline for SVC. PB-100 schematic
planning may proceed after freeze. KiCad PCB layout remains blocked until
schematic inputs are reviewed.

Architecture v1.0 was accepted by the project owner on 2026-06-30 and frozen in
ADR-0009.

## 1. Architecture goal

Design a modular smart vehicle controller that can support future features primarily through configuration, plugins, firmware, or Logic Board replacement.

The primary lifecycle constraint is that PB-100 must remain stable while LB-100,
FB-100, firmware, configuration, and vehicle profiles evolve.

## 2. Board architecture

```text
Power Board PB-100
        ▲
        │ 100-pin mezzanine / board-to-board interface
        │
Logic Board LB-100
        ▲
        │ board-to-board / cable
        │
Front Panel Board FB-100
```

### 2.1 Board responsibilities

| Board | Responsibility | Expected change rate |
|---|---|---|
| PB-100 | Vehicle power input, protected generic outputs, current/thermal sensing, fuse interface, high-current connectors | Low |
| LB-100 | MCU, firmware execution, CAN/LIN/RS485/UART interfaces, storage, RTC/FRAM, sensors, rule engine | Medium |
| FB-100 | USB-C service access, service button, status indication | Medium |

PB-100 exposes generic power capabilities. It must not encode accessory roles in
silkscreen, net names, firmware constants, or mechanical assumptions beyond
neutral output identifiers such as OUT1..OUT10.

## 3. Power domains

- Always-on logic domain
- Switched accessory domain
- High-current domain
- Sensor domain
- Service/programming domain

Power-domain requirements:

- PB-100 accepts vehicle battery input and must tolerate the system electrical
  requirements in `docs/requirements/system-requirements.md`.
- A main fuse is installed near the battery in the harness.
- Per-output fuses are user-serviceable.
- Reverse-polarity, surge/transient, and ESD protection are required before
  schematic freeze.
- Logic power must remain stable through normal motorcycle cranking dips where
  practical.

## 4. Required outputs

PB-100 must provide at least 10 generic protected outputs:

| Output | Reference default role | Target fuse | Target current limit | PWM |
|---|---|---:|---:|---|
| OUT1 | Cigarette socket / future compressor | 15 A | 12 A | yes |
| OUT2 | High-current reserve | 20 A | 18 A | optional |
| OUT3 | Fog primary left | 10 A | 8 A | yes |
| OUT4 | Fog primary right | 10 A | 8 A | yes |
| OUT5 | Low-current reserve 1 | 5 A | 4 A | yes |
| OUT6 | Fog secondary left | 10 A | 8 A | yes |
| OUT7 | Fog secondary right | 10 A | 8 A | yes |
| OUT8 | Low-current reserve 2 | 5 A | 4 A | yes |
| OUT9 | Low-current reserve 3 | 5 A | 4 A | yes |
| OUT10 | Medium-current reserve | 10 A | 8 A | yes |

Reference default roles are configuration defaults for Vehicle Profile #001 only.
They are not hardware roles.

ADR-0020 additionally defines the independent `C36_BIDIRECTIONAL` battery
branch and the protected `FOG_A_SW_IN`/`FOG_B_SW_IN` manual requests. Neither changes the
generic OUT1 through OUT10 PCB naming or permits firmware to bypass safe-off.

## 5. Each output must support

- Fuse
- High-side electronic switching
- PWM where applicable
- Current measurement
- Overcurrent protection
- Thermal derating
- Fault lockout
- Role assignment by configuration
- Load priority assignment by configuration
- Safe default-off state during boot, reset, firmware update, and fault recovery

Detailed PB-100 requirements are tracked in
`docs/requirements/pb-100-requirements.md`.

## 6. Vehicle network

- CAN1: vehicle CAN, read-only by default
- CAN2: expansion / bench / accessory CAN
- LIN footprint
- RS485 footprint
- UART expansion

CAN1 requirements:

- CAN1 is physically listen-only by default.
- CAN1 TX must be disabled by solder jumper, hardware gate, or transceiver
  silent/listen-only mode.
- Rev.1 firmware must not transmit on vehicle CAN.
- Any future CAN TX support requires a new ADR and an explicit hardware-enable
  action.

CAN2 is the only CAN interface intended for bench, expansion, or accessory
transmit use in the v1.0 architecture.

## 7. Sensors

- Battery voltage
- Total input current
- Per-channel current
- PCB temperature
- MOSFET/power-zone temperature
- Ambient light sensor
- IMU
- External temperature input
- RTC
- FRAM
- Optional barometer/humidity footprint

## 8. Software architecture

```text
Drivers
  ↓
Event Bus
  ↓
Services
  ↓
Rule Engine
  ↓
Output Manager
  ↓
Logger / API
```

No module should directly manipulate another feature. CAN creates events; rules consume events; output manager applies actions.

Required software boundaries:

- Drivers expose hardware state and commands.
- Services own debouncing, filtering, diagnostics, and state transitions.
- The event bus is the only cross-feature notification path.
- The rule engine consumes events and configuration.
- The output manager is the only module that applies output state changes.
- Logging/API modules observe events and state; they do not bypass services.

## 9. Configuration

Configuration is separate from firmware and contains:
- channel role mapping
- current limits
- board-level total current budget
- PWM limits
- profiles
- IF/THEN rules
- battery thresholds
- vehicle profile
- CAN database selection

Configuration storage requirements:

- Firmware updates must not erase user configuration.
- Vehicle profiles define default role mappings and CAN database selection.
- Hardware capability discovery must use board identifiers and capabilities, not
  accessory role assumptions.
- Invalid configuration must fail safe with outputs disabled or held in the last
  explicitly safe state.

The current example configuration is
`firmware/configs/config-example.json`.

## 10. Manufacturing

- SMD parts assembled by PCBWay/JLCPCB.
- User installs only connectors, fuses, enclosure hardware, wiring.
- Components should preferably be available through LCSC/JLCPCB assembly.
- Critical components must have alternatives.
- Component-family selection must be verified before schematic freeze.
- Factory BOM and garage BOM remain separate production artifacts.
- Initial component-family shortlist is tracked in
  `docs/production/component-family-shortlist.md`.

## 11. Reference vehicle

BMW R1200GS K25 2007 is the first integration target.

Vehicle Profile #001 requirements:

- BMW CAN remains read-only.
- Accessory roles map to OUT1..OUT10 through configuration.
- Fog light, brake-light, and accessory behavior must be implemented through
  events, rules, and output manager actions.
- The platform must remain vehicle-agnostic after applying the BMW K25 profile.

## 12. Board-to-board interface contract

The PB-100 to LB-100 interface must carry these signal classes:

- Power: protected battery sense, logic supply, power-good, grounds.
- Output control: enable/PWM command signals for each generic output.
- Measurement: per-output current telemetry, input voltage/current telemetry,
  and temperature telemetry.
- Faults: per-output fault indication and board-level fault indication.
- Expansion: spare GPIO/ADC/I2C/SPI/UART capacity for future PB-100 revisions.
- Safety: CAN1 TX disable control/status when applicable.

The exact pin map is a schematic-freeze artifact. The interface must keep PB-100
usable with future LB-100 revisions without changing PB-100 connectors or output
stage design.

## 13. Freeze checklist

Architecture v1.0 is frozen because all items are true:

- ADR-0001 through ADR-0009 are accepted.
- PB-100 requirements are reviewed and accepted.
- CAN1 read-only hardware policy is preserved in schematic requirements.
- Output role mapping remains configuration-driven.
- Board-level current budget and priority shedding are defined.
- Critical component families have at least two viable alternatives.
- Initial component-family shortlist is complete.
- Factory and garage BOM split remains valid.
- No KiCad layout work has started before requirements acceptance.

## 14. Review outcome

This review authorizes PB-100 schematic planning. It does not authorize PCB
layout or Power Board requirement changes without a follow-up ADR.

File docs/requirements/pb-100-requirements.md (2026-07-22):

# PB-100 Power Board Requirements

Status: Baseline candidate

PB-100 is the stable power-stage board for the SVC platform. It must remain
vehicle-agnostic and must not encode accessory roles in hardware.

## 1. Lifecycle

- Target lifecycle: 10-15 years where practical.
- New features must prefer configuration, plugins, firmware, or LB-100 changes
  before PB-100 changes.
- PB-100 requirement changes require an ADR.

## 2. Electrical input

- Normal operating input target: 6-18 V.
- Must tolerate motorcycle cranking dips where practical.
- Requires main fuse near the battery in the harness.
- Requires reverse-polarity protection.
- Requires automotive transient/load-dump protection strategy before schematic
  freeze.
- Requires battery voltage and total input current measurement.

### 2.1 Load-dump design envelope

- ISO 16750-2 Test A design evidence must cover `Us = 79-101 V`,
  `Ri = 0.5-4 ohm`, and `td = 40-400 ms` at cold and hot initial junction
  conditions.
- The final qualification plan must cover ten pulses with 60 s spacing.
- Evidence must calculate cutoff tolerance, source current, switch transition
  energy, MOSFET dynamic SOA, transient thermal impedance, junction
  temperature, self-heating, and layout/measurement uncertainty. Any populated
  suppression device also requires current, power, energy, and thermal proof.
- The selected Rev.1 branch must disconnect the load at no more than `55 V`;
  load interruption during load dump is explicitly permitted. Post-layout
  extraction must keep `VBAT_PROT` below the 60 V protected-domain limit.
- Passing a peak clamp-voltage check alone does not satisfy the requirement.
- See ADR-0016 and ADR-0018.

## 3. Generic outputs

PB-100 must provide at least 10 generic protected outputs.

| Output | Reference default role | Target fuse | Target current limit | PWM |
|---|---|---:|---:|---|
| OUT1 | Cigarette socket / future compressor | 15 A | 12 A | yes |
| OUT2 | High-current reserve | 20 A | 18 A | optional |
| OUT3 | Fog primary left | 10 A | 8 A | yes |
| OUT4 | Fog primary right | 10 A | 8 A | yes |
| OUT5 | Low-current reserve 1 | 5 A | 4 A | yes |
| OUT6 | Fog secondary left | 10 A | 8 A | yes |
| OUT7 | Fog secondary right | 10 A | 8 A | yes |
| OUT8 | Low-current reserve 2 | 5 A | 4 A | yes |
| OUT9 | Low-current reserve 3 | 5 A | 4 A | yes |
| OUT10 | Medium-current reserve | 10 A | 8 A | yes |

Reference default roles are initial configuration defaults for BMW K25 Vehicle
Profile #001. Physical outputs remain generic.

The stock headlamp remains on factory wiring. The LOBOO C36 is the separate
`C36_BIDIRECTIONAL` battery branch defined by ADR-0020 and is not OUT1 through
OUT10. The four auxiliary-lamp nameplate values are provisional until EVT
measurement. `FOG_A_SW_IN` and `FOG_B_SW_IN` are independent configurable user
requests for the reference OUT3/OUT4 and OUT6/OUT7 pairs; Output Manager retains
all budget, voltage, telemetry, thermal and fault authority.

The reference fuse ratings total 100 A and the reference current limits total
82 A. This is intentionally higher than the board-level continuous-current
budget. See ADR-0008.

## 4. Per-output requirements

Each output must support:

- User-serviceable fuse.
- High-side electronic switching.
- PWM where listed.
- Current measurement.
- Overcurrent protection.
- Thermal derating.
- Fault lockout.
- Configuration-based role assignment.
- Configuration-based current limit and priority.
- Safe default-off state during boot, reset, update, and fault recovery.

## 5. Board-level current budget

- Main harness fuse target: 50 A.
- Board continuous-current design target: at least 40 A after thermal validation.
- Default firmware/configuration total-current limit: 40 A.
- Outputs are allowed to be over-subscribed relative to the board budget.
- Firmware must refuse startup or shed lower-priority loads when the configured
  board-level budget would be exceeded.
- Total input current measurement is required for budget enforcement.
- `IIN_SENSE`, rather than only the sum of channel IMON readings, enforces the
  40 A managed-board budget.
- Mutually exclusive loads are evaluated through the configured operating-mode
  matrix and are not treated as simultaneously permitted.

## 6. Thermal and diagnostics

- Requires PCB temperature measurement.
- Requires power-zone temperature measurement.
- Must expose output fault status to LB-100.
- Must support firmware-visible diagnostic state for overcurrent, thermal
  derating, fuse/open-load suspicion where practical, and lockout.

## 7. Vehicle network safety

- PB-100 must not require vehicle CAN TX for any core function.
- If CAN1 routing or transceiver support crosses PB-100, CAN1 TX disable must be
  physically enforced by default.
- Any CAN1 TX enable path requires a new ADR and an explicit hardware action.

## 8. Board interface

PB-100 must expose a stable board-to-board interface to LB-100 for:

- Power and ground.
- Output enable/PWM commands.
- Current, voltage, and temperature telemetry.
- Fault/status signals.
- Board identity or revision identification where practical.
- Reserved expansion capacity.

The exact pin map is deferred to schematic freeze.

## 9. Manufacturing

- Fine-pitch and small SMD parts are factory assembled.
- User-installed parts are limited to connectors, fuses, enclosure hardware, and
  wiring.
- Critical component selections require at least two alternatives.
- Component availability for JLCPCB/PCBWay assembly must be checked before
  schematic freeze.
- Initial component-family shortlist is tracked in
  `docs/production/component-family-shortlist.md`.

## 10. Acceptance criteria

PB-100 requirements are ready for schematic planning when:

- ADR-0006 is accepted.
- ADR-0007 is accepted.
- ADR-0008 is accepted.
- Output count and protection model are stable.
- CAN read-only policy is preserved.
- Board-level current budget is documented.
- Factory/garage BOM split is still valid.
- Component-family shortlist exists with alternatives for critical parts.

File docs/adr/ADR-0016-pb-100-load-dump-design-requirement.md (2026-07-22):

# ADR-0016: PB-100 Load-Dump Design Requirement

Status: Accepted — release authorization superseded in part by ADR-0019

Date: 2026-07-21

## Context

PBREL-007 was closed using a 100 V, 10/1000 us pulse and a peak-voltage-only
screen. That waveform does not represent the 40-400 ms duration of the ISO
16750-2 12 V load-dump envelope and therefore does not prove TVS energy or
thermal survival. The former 59.45 V result also left only 0.55 V to the
LM74700-Q1 60 V recommended input ceiling before full tolerance, dynamic
resistance, self-heating, layout parasitics, and measurement uncertainty were
known.

The Product Owner directed a corrective review. This ADR changes the PB-100
protection requirement and evidence gate; it does not change the frozen
vehicle-agnostic power-board architecture.

## Decision

PB-100 load-dump design evidence shall cover the ISO 16750-2 Test A 12 V design
envelope at all corners of:

- open-circuit source voltage `Us = 79-101 V`;
- source resistance `Ri = 0.5-4 ohm`;
- pulse duration `td = 40-400 ms`;
- cold and hot initial junction conditions;
- ten pulses with 60 s spacing for the final qualification plan.

Pre-layout evidence shall calculate TVS current, clamp voltage, instantaneous
power, absorbed energy, transient thermal impedance, predicted junction
temperature, tolerance effects, temperature coefficient, dynamic resistance,
self-heating, and explicit parasitic/measurement uncertainty.

The protected LM74700-Q1 node shall retain at least `5 V` modeled margin to the
60 V recommended ceiling at every accepted corner. The 65 V absolute maximum
is a destructive boundary, not design margin. Passing the 80 V MOSFET voltage
class does not close controller or TVS thermal evidence.

ADR-0018 rejects the current SM8S33AHM3/I branch as the active energy sink and
selects LM74930-Q1 hard cutoff with a 150 V raw-side MOSFET. The PBREL-007
pre-layout stage is now closed by generated cutoff and transient-SOA evidence.
Extracted-loop review and PB-BENCH-004 remain separate post-layout and
prototype-qualification stages under ADR-0017. PBREL-006 retains accepted
pre-layout Q1 selection evidence; copper/thermal extraction and PB-BENCH-010
remain its separate post-layout and prototype-qualification stages.

## Consequences

- The former 10/1000 us result remains historical rejected evidence only.
- A TVS with adequate peak clamp but inadequate energy or transient thermal
  performance cannot close PBREL-007.
- TVS arrays, staged suppression, higher-power parts, or controller isolation
  may be compared without removing required capabilities; any architecture
  change still needs Product Owner approval and another ADR.
- ADR-0019 authorizes controlled Rev.1 EVT layout and a five-board EVT package
  after routed-board DRC and pre-fab review even while PBREL-007 remains
  Conditional. The load-dump evidence in this ADR blocks
  `PRODUCTION-RELEASE`, not `EVT-LAYOUT-AUTHORIZED` or a reviewed
  `EVT-FAB-AUTHORIZED` package. Production and general field release remain
  prohibited until bench, motorcycle, Rev.2 and normal production gates close.

## Evidence

- TI automotive load-dump application brief:
  https://www.ti.com/lit/ab/snoaaa1/snoaaa1.pdf
- Vishay SM8S33AHM3/I datasheet:
  https://www.vishay.com/docs/98647/sm8s85ahm3.pdf
- TI LM74700-Q1 datasheet:
  https://www.ti.com/lit/ds/symlink/lm74700-q1.pdf
- `hardware/power-board/PB-100/PB-100-transient-margin-evidence.csv`

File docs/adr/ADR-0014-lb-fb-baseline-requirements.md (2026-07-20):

# ADR-0014: Freeze LB-100 and FB-100 baseline requirements for schematic planning

## Status
Accepted

## Context
SVC is a three-board platform: PB-100, LB-100, and FB-100. PB-100 now has a
schematic-planning package and board-release gates, but LB-100 and FB-100 only
had requirements notes. A JLCPCB/PCBWay order for the product cannot be treated
as ready while the logic and front boards have no explicit freeze gates.

## Decision
Freeze the Rev.1 baseline requirements for LB-100 and FB-100 so schematic
planning and non-layout KiCad scaffolding may proceed.

LB-100 Rev.1 baseline:

- STM32H563 LQFP-100 remains the default target from ADR-0005.
- STM32H573 remains an accepted alternative when security requirements justify
  cost and sourcing risk.
- PB-100 provides a protected `PB_5V_OUT` allocation of 500 mA sustained unless
  LB-100 schematic review proves a higher-current requirement.
- CAN1 vehicle access remains read-only by default and cannot be enabled by
  configuration or firmware alone.
- LB-100 owns firmware execution, CAN/LIN/RS485/UART interfaces, USB service
  path, BLE, microSD, RTC, FRAM, IMU, lux sensing, and external inputs.
- Sleep, deep-sleep, wake, and back-power behavior must satisfy ADR-0012 before
  vehicle installation.

FB-100 Rev.1 baseline:

- FB-100 is the service and local UI board.
- It carries USB-C service access, RGB/status indication, channel indication,
  SERVICE/RESET button behavior, and an optional OLED footprint.
- FB-100 must not encode vehicle accessory roles; indicators map to logical
  status/channel signals.
- FB-100 must not back-power LB-100 or PB-100 through USB, signal lines, or
  button/LED circuitry without an explicit reviewed power path.

This ADR does not change PB-100 requirements and does not authorize PCB layout,
Gerbers, drill files, pick-place files, BOM/CPL order packages, or PCBA orders.

## Consequences
LB-100 and FB-100 must gain their own schematic-freeze checklists, blocker
registers, and release manifests before any board-order package is considered.

The project-level board-order gate must report all three boards. A three-board
JLCPCB/PCBWay order remains NO-GO until PB-100, LB-100, and FB-100 each have
closed schematic freeze, reviewed KiCad schematic/layout files, fabrication
outputs, and assembly/order evidence.

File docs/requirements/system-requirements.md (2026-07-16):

# System Requirements

## Environmental
- Operating voltage: 6–18 V normal target
- Must tolerate motorcycle cranking voltage dips
- Automotive transient protection required
- Target temperature range: -40°C to +85°C where practical
- Vibration-resistant connectors and mounting

## Safety
- Main fuse near battery
- Per-channel fuse
- MOSFET/eFuse protection
- Low battery shutdown
- Thermal derating
- Watchdog
- Recovery mode
- CAN read-only default
- Safe default-off output state during boot/reset/update/fault
- Board-level current budget enforcement
- Priority-based load shedding

## Sleep, wake, and parking current
- Device is permanently battery-connected and must define off-ignition current
  budgets before final LB-100 power selection.
- Sleep mode target current at battery input: ≤1.0 mA; hard maximum: ≤2.0 mA.
- Deep-sleep target current at battery input: ≤250 µA; hard maximum: ≤500 µA.
- Enter sleep within 60 seconds after ignition/accessory-off when no service
  session or configured delayed-output action is active.
- Enter deep sleep within 24 hours of continuous parking.
- Allowed Rev.1 wake sources: ignition/accessory sense, USB/service power,
  service button, RTC/maintenance timer, and listen-only CAN1 wake only if CAN1
  TX remains physically disabled.
- All PB-100 outputs remain off in sleep and deep sleep unless a future ADR
  explicitly defines a wake-safe always-on output class.
- Maximum parking drain budget: ≤0.35 Ah over the first parked week and ≤0.45 Ah
  over one parked month after deep sleep transition.

## Manufacturing
- SMD factory assembly
- THT/large connectors installed manually
- Production BOM and Garage BOM separated
- Critical components have alternatives

## Software
- FreeRTOS preferred
- Event bus architecture
- Rule engine
- JSON/CBOR configuration
- Separate firmware and configuration
- USB-C service mode
- BLE configuration
- microSD logging

## Power Board
- PB-100 requirements are tracked in `docs/requirements/pb-100-requirements.md`
- PB-100 requirement changes require ADR approval

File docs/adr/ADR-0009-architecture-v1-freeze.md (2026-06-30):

# ADR-0009: Freeze SVC architecture v1.0

## Status
Accepted

## Context
Architecture Review v1.0 reached freeze candidate status after the core safety,
manufacturing, output-mapping, component-family, high-side switching, and
current-budget decisions were accepted.

The project owner approved continuing implementation on 2026-06-30.

## Decision
Freeze SVC architecture v1.0 as the baseline for PB-100 schematic planning,
LB-100 firmware architecture, and production planning.

The frozen baseline includes:
- Three-board architecture: PB-100, LB-100, FB-100.
- Read-only vehicle CAN by default.
- Generic output channels with configuration-based role mapping.
- PB-100 high-side output switching.
- PB-100 board-level current budget.
- Factory SMD assembly with separate garage BOM.
- Initial component-family shortlist with alternatives.

## Consequences
PB-100 schematic planning may begin.

Power Board requirement changes still require an ADR. KiCad PCB layout remains a
separate implementation step and must not start until schematic requirements,
pin budget, and component families are reviewed.

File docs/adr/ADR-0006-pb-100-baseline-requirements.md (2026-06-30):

# ADR-0006: PB-100 baseline requirements

## Status
Accepted

## Context
PB-100 is the long-lifecycle board. It carries the highest electrical,
thermal, wiring, and manufacturing risk in the SVC platform.

## Decision
PB-100 will provide at least 10 generic protected outputs with per-channel fuse,
switching, current measurement, overcurrent protection, thermal derating, fault
lockout, and configuration-based role assignment.

PB-100 requirements are tracked in
`docs/requirements/pb-100-requirements.md`. Future changes to PB-100 output
count, protection model, role-mapping model, or vehicle-CAN safety behavior
require a new ADR.

## Consequences
Architecture and firmware can evolve around a stable power-stage contract.
Schematic planning may begin only after these requirements are accepted, but PCB
layout remains blocked until architecture freeze.

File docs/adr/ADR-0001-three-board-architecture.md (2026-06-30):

# ADR-0001: Use three-board architecture

## Status
Accepted

## Context
The device must live for many years. The power stage should not be redesigned when MCU, connectivity, or UI changes.

## Decision
Use three boards:
- PB-100 Power Board
- LB-100 Logic Board
- FB-100 Front Panel Board

## Consequences
Power Board can remain stable while Logic Board evolves.

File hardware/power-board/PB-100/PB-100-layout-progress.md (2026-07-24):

# PB-100 Controlled Layout Progress

Status: `EVT-LAYOUT-AUTHORIZED` — routed baseline exists; `EVT-FAB-REVIEW` remains blocked

## Completed Milestone

- Generated the controlled eight-layer `kicad/PB-100.kicad_pcb` with the
  reviewed 150 mm x 90 mm outline, four local M3 holes and four shared M2.5
  PB/LB stack holes. The stack keeps In2.Cu as the continuous GND reference
  and In5.Cu as the protected-battery distribution plane.
- Imported and placed all 414 footprint-bound schematic parts plus eight
  board-only mounting holes. Schematic parity is closed except for the eight
  intentional mounting-hole footprints.
- Preserved the accepted architecture: ten generic outputs, configuration-
  mapped channel roles, the 40 A board target, removable input isolation,
  factory/DNP alternatives, and the physically default-disabled CAN1 TX path.
- Added explicit battery-entry and output-current zones, protected-bus
  transitions and conventional through-via fields. The broad generated
  segments and zones remain the only copper credited to the high-current path;
  preliminary 0.20 mm attachment traces are not current-capacity evidence.
- Recorded 5,778 deterministic routing-manifest items in
  `kicad/PB-100-routing.csv`: 5,016 segments and 762 conventional through
  vias. Together with generator-owned power copper, the board contains 5,049
  segments, 874 vias and 38 zones.
- Added deterministic route export, residual-route handling and validation.
  A clean regeneration followed by KiCad 10.0.4 zone refill reports no shorts,
  track crossings, copper-clearance, edge-clearance, drill or keepout
  violations introduced by this routing baseline.
- Reduced open connectivity from 499 to 36. The DRC-clean closeout includes
  the previously trapped `LB_3V3_IO`, `PB_I2C_INT`, `OUT1_IWRN` and
  `OUT2_IWRN` branches. Dense controller fan-out was recovered with local
  signal-layer jogs and 0.60/0.30 mm filled/capped conventional through vias;
  no blind or buried vias were introduced. The remaining items are explicit
  blockers rather than hidden or waived connections.

## EVT-FAB Blockers

- Close all 36 remaining connections. The largest groups are 14 GND
  pad/pour/plane fragments, four `OUT7_SWITCHED` branches, three
  `VBAT_PROT` attachments, two `VBAT_REV_PROT` branches and two
  `OUT4_SWITCHED` branches. Eleven single residuals remain across controller
  support, timing/sense, output-zone and power-option nets.
- Replace preliminary attachment routing where required by the final
  current/thermal model. In particular, close the protected 5 V and 3.3 V rail
  widths, buck switch loop, clamp-current returns, CAN1 coupled-pair geometry
  and all high-current zone neck/current-density evidence before fabrication.
- Resolve the current project-context refilled warning baseline: 27
  project-library footprint mismatches, eight project-library footprint
  issues, 136 silk-over-copper findings, nine starved thermals and 17
  silkscreen overlaps.
- Close 40 A electrothermal extraction, Q1/Q2 and output clamp-loop parasitics,
  connector fit, probe/safety fixture access, supplier stack/DFM review and
  Product Owner pre-fabrication approval.

This routed baseline is not suitable for fabrication. No Gerbers, drills,
pick-place, manufacturing ZIP or order package is authorized or generated.
`PBREL-007` remains a separate `PRODUCTION-RELEASE` blocker.

Reason: ADR-0020 authorizes placement, routing and pours, but not fabrication.
The current milestone preserves the accepted architecture and gives the
remaining work a deterministic, DRC-checked starting point without treating
autorouter connectivity or thin attachment traces as 40 A, EMC, thermal or
production evidence.

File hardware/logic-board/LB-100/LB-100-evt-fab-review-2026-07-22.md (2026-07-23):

# LB-100 Rev.1 EVT Fabrication Review — 2026-07-22

Status: `EVT-FAB-AUTHORIZED`; five-board bare-PCB package may be released only
through the recorded EVT controls below

## Release scope

This review covers one segregated batch of five bare LB-100 Rev.1 EVT boards
for bench bring-up and measurements. It does not authorize PB-100, a combined
three-board order, production use, motorcycle installation, BOM/CPL release or
assembled PCBA procurement.

The Product Owner explicitly requested completion of LB-100 and preparation of
test boards on 2026-07-22. That instruction is recorded as authorization for
the limited LB-only fabrication package after repository checks pass. The
supplier upload must still be stopped if DFM changes the stack, copper, drill,
outline, impedance or connector geometry.

## Electrical and fabrication evidence

- 104 schematic footprints plus H1-H8; 199 nets.
- 2,274 deterministic segments and 409 standard 0.50/0.30 mm plated through
  vias; no blind/buried vias or HDI process.
- Four GND zones on F.Cu, In2.Cu, In4.Cu and B.Cu.
- KiCad 10.0.4 after refill: zero errors and zero unconnected items.
- Schematic parity: H1-H8 only, all intentional board-only NPTH mounting holes.
- Stack: JLCPCB `JLC06161H-3313`, six layers, 1.6 mm, ENIG. In2.Cu and In4.Cu
  are uninterrupted reference planes; no routing rows are allowed on them.
- The exact six-layer E73 no-copper rule is validator-covered.
- All five E73 recovery pads and every frozen ADC, I2C, FOG, SD, clock, USB,
  UART, SWD, safety-control and JPB1 net are connected. Existing schematic and
  exported-netlist validators continue to enforce the safe-boot, Ioff,
  read-only CAN1 and mutually-exclusive FOG population contracts.

## USB review

`USB_D_P` and `USB_D_N` use 0.20 mm traces on In3.Cu over the In2.Cu GND
reference through the central 0.1088 mm 2116 dielectric. The long parallel
segments have approximately 0.157 mm edge gap. Total routed lengths are
37.643 mm and 38.754 mm, so skew is 1.112 mm. Each grouped layer transition has
a GND via within 4 mm.

An IPC-style regression estimate is approximately 85 ohm differential. This
is not supplier field-solver evidence. During JLCPCB upload select
`JLC06161H-3313`, request 90-ohm differential control, and accept the order
only if the supplier calculator/engineering review keeps the pair within its
stated process tolerance without an unreviewed geometry change:

- <https://jlcpcb.com/resources/6-layer-pcbs>
- <https://jlcpcb.com/impedance>
- <https://jlcpcb.com/help/article/user-guide-to-the-jlcpcb-impedance-calculator>

## Connector and storage review

JFB1 is JUSHUO `AFC07-S24ECA-00` / LCSC `C262643`: 24 positions, 0.5 mm pitch,
top contact, slide lock, right angle and 0.3 mm FFC. LB places it on F.Cu at
`(6,35)`, rotation +90 degrees, with the cable opening at the left edge. The FB
mate is on B.Cu with the opposite edge entry. Electrical pin numbering is
validator-covered; actual cable contact face, fold, bend radius and both latch
accesses remain a first-article unpowered fit inspection:

- <https://www.lcsc.com/product-detail/C262643.html>

The SOFNG TF-015 drawing specifies two 1.00 mm mechanical locating holes. They
are NPTH in the local footprint; the socket signal/shell lands remain SMT:

- <https://www.sofng.com/Memory/T_Flash_CARD_SOCKETS/list_58_4.html>
- <https://xonstorage.z8.web.core.windows.net/pdf/sofng_tf015_apr22_xonlink.pdf>

## Warning disposition and first-article controls

The 27 KiCad warnings are limited to reviewed silkscreen clips, generated
board-hole library notices and three known local footprint transforms. There
are no copper, mask, drill, courtyard, clearance or connectivity errors.

Before payment:

1. Run supplier DFM and confirm the exact six-layer stack and 90-ohm request.
2. Confirm all Gerber layers, NPTH/PTH drill split, 100 mm x 70 mm outline and
   five-piece quantity in the preview.
3. Do not approve any automatic reroute, layer reduction or drill substitution.

Before powering the first assembly:

1. Inspect JPB1 pin 1, all six FX18 mechanical lands and the four GND MF nets.
2. Dry-fit the actual FFC and microSD card; record contact side and latch access.
3. Inspect polarity, DNP selections and shorts; power from a current-limited
   bench supply.
4. Measure BLE range in the intended enclosure. RF evidence remains a
   production/Rev.2 gate.

The combined platform remains `NO-GO` until PB-100 is completed and each board
passes its own release gate.

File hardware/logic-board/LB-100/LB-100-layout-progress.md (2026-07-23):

# LB-100 Controlled Layout Progress

Status: `EVT-FAB-AUTHORIZED` — one segregated five-board bare-PCB Rev.1 EVT package is authorized

## Completed milestone

- The deterministic six-layer `kicad/LB-100.kicad_pcb` implements the frozen
  104-component/199-net schematic on the reviewed 100 mm x 70 mm outline.
- The route manifest contains 2,274 segments and 409 conventional
  `0.50/0.30 mm` F.Cu-to-B.Cu plated through vias. No blind, buried or
  microvias are used.
- KiCad 10.0.4 zone-refill DRC reports zero errors and zero unconnected items.
  Schematic parity contains only H1-H8, the intentional board-only mounting
  holes.
- The six-layer `JLC06161H-3313` model is committed: F.Cu and B.Cu signal,
  In1.Cu and In3.Cu signal, and continuous GND references on In2.Cu and
  In4.Cu. GND pours are also present on F.Cu and B.Cu.
- U7 faces the +Y edge. Its rule area covers all six copper layers and forbids
  tracks, vias, pads and pours beyond the terminal end.
- The E73 SWDIO, SWDCLK, reset, switched target reference and GND recovery
  pads are accessible and routed.
- The USB Full-Speed pair uses 0.20 mm traces on In3.Cu above the In2.Cu GND
  plane. Its parallel section has approximately 0.157 mm edge gap, total route
  skew is 1.112 mm, and the analytical regression estimate is approximately
  85 ohm differential. Supplier field-solver confirmation remains an order
  preflight requirement, not a claimed qualification result.
- The two TF-015 locating features are now 1.00 mm NPTH holes, matching the
  official SOFNG mechanical drawing instead of electrically plated pads.

## Reviewed DRC warnings

The refill report contains 27 warnings and no errors:

- 10 silk-over-mask-pad clips on small footprints;
- 6 silk-to-edge clips at the intentional E73 and TF-015 board-edge entries;
- 8 missing-library notices for generated board-only H1-H8 footprints;
- 3 known generated local footprint transforms for JPB1, JSD1 and JBT1.

These findings affect legend/library comparison only. None changes copper,
mask openings, drill geometry, connectivity or courtyard clearance. The
fabricator may clip the affected silkscreen. The validator locks the exact
warning set so a new electrical or mechanical finding cannot hide in it.

## Remaining EVT order controls

- Select the exact `JLC06161H-3313` stack in the supplier order and accept only
  a field-solver result inside the USB 90-ohm order tolerance; otherwise return
  the board for a width/gap update.
- JFB1 is JUSHUO `AFC07-S24ECA-00`: 24 positions, 0.5 mm pitch, top contact,
  slide lock, 0.3 mm FFC. Verify cable contact side, insertion direction, bend
  radius and latch access on the first unpowered LB/FB stack.
- Treat the 0.15 mm E73 keepout margin as a Rev.1 experiment. Measure BLE range
  in the actual enclosure before production/Rev.2.
- Run the supplier's automated DFM on the segregated LB-only package before
  payment. Any stack, drill, outline, clearance or impedance substitution
  requires review; it is not an automatic waiver.
- The first five units remain `LB-100 REV.1 EVT - NOT FOR PRODUCTION` and may
  be used only for bench bring-up and measurements before motorcycle testing.

PB-100 and the combined three-board order remain `NO-GO`; this milestone does
not authorize PB or production outputs.

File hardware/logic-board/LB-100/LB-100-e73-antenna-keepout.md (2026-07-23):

# LB-100 E73 Antenna Keepout

Status: implemented for Rev.1 EVT; production RF qualification remains open

## Source boundary

The selected module is Ebyte `E73-2G4M08S1C`. The official product page and
user manual identify the 2.4 GHz ceramic-antenna variant and give the module,
terminal and antenna-end geometry:

- <https://www.ebyte.com/product/444.html>
- <https://www.ebyte.com/Uploadfiles/Files/2018-8-7/2018871547597144.pdf>

The manual does not specify a numeric host-PCB antenna keepout. The LB-100
boundary is therefore a project-derived Rev.1 rule based on the official
terminal drawing and reviewed local footprint. It is not an Ebyte-certified
keepout.

## Implemented geometry

- U7 datum: `(72.0 mm, 59.0 mm)`, rotation `0 degrees`.
- The ceramic-antenna end faces the `+Y` board edge.
- Terminal copper ends at board `Y=66.46 mm`; the keepout starts at
  `Y=66.61 mm` and continues to `Y=70.00 mm`.
- X boundary: `65.35..78.65 mm`, including 0.15 mm lateral margin.
- Layers: `F.Cu`, `In1.Cu`, `In2.Cu`, `In3.Cu`, `In4.Cu`, and `B.Cu`.
- Tracks, vias, pads and copper pours are forbidden inside the boundary.
- F.Cu, In2.Cu, In4.Cu and B.Cu GND zones stop at the keepout during refill.

The geometry is emitted by `tools/generate_lb100_layout.py` and verified by
`tools/validate_lb100_layout.py`.

## Verification and residual risk

KiCad 10.0.4 reports no `items_not_allowed`, short, clearance, crossing or
unconnected finding after refill. This proves the implemented no-copper rule,
not RF range.

For the five Rev.1 EVT units:

- inspect antenna orientation and pin 1 before power-up;
- keep cells, shields, standoffs, metallization and cable bundles out of the
  antenna volume;
- record enclosure material and air gap;
- measure current and over-the-air range during bench EVT.

Production/Rev.2 RF readiness remains blocked until the real enclosure and
range results justify retaining or enlarging the project-derived boundary.

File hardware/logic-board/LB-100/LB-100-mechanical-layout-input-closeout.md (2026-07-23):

# LB-100 Mechanical Layout Input Closeout

Status: Closed for pre-layout mechanical input

The JPB1 pair, 20 mm stack, four-spacer retention pattern, assembly fixture,
mating inspection, and six official plated lands with four GND MF circuits are
closed in the PB/LB paired-stack closeout. Actual stack and vibration records
remain post-prototype PB-BENCH-014/015 evidence under ADR-0013. LB-100 board
import, placement and routing are authorized by ADR-0020. Signal-integrity and
safety evidence must close during `EVT-FAB-REVIEW` before prototype fabrication.
Review date: 2026-07-20

This closeout converts the LB-100 pre-layout mechanical envelope into reviewed
layout-input dimensions. It does not create `LB-100.kicad_pcb`, Gerbers, drill
files, pick-place files, BOM/CPL order packages, manufacturing ZIP files,
fabrication packages, panel CAD, enclosure CAD, harness drawings, or PCBA
orders.

## Why The Blocker Existed

LB-100 had closed requirements, schematic review, and footprint-binding
evidence, but board import still lacked reviewed mechanical inputs for the
outline, mounting holes, PB/LB JPB1 stack datum, STM32H563VITx service access,
power-rail placement, microSD access, BLE antenna keepout, IMU/lux sensor
orientation, and service/expansion connector keepouts.

The blocker was valid because LB-100 carries safety-relevant vehicle interfaces
and service paths. Starting board import without a mechanical datum could place
CAN1_TX_ROUTE, RF, storage, sensors, or debug access in positions that conflict
with the PB-100 stack or future enclosure serviceability.

## Candidate Comparison

| Area | Candidate A | Candidate B | Selection |
|---|---|---|---|
| Outline | 100 mm x 70 mm rectangular prototype | Match PB-100 full outline | 100 mm x 70 mm prototype outline |
| Mounting | Four M2.5 local holes | Share PB-100 M3 holes | Four M2.5 local holes |
| JPB1 placement | Centered FX18 datum | Edge-biased stack | Centered datum |
| MCU access | Central service corridor | Hide MCU under stack | Central service corridor |
| Power rails | Near JPB1 with no-back-power zone | Near USB/service edge | Near JPB1 |
| microSD | Right-edge service access | Internal-only card slot | Right-edge access |
| BLE | Top-right edge antenna keepout | Interior antenna placement | Edge antenna keepout |
| Sensors | Documented board axes | Vehicle-specific axis assumption | Documented board axes |
| Expansion | DNP/service lower-edge keepouts | Dedicated vehicle-role connectors | Generic DNP/service keepouts |

## Recommended Solution

Use `LB-100-mechanical-layout-inputs.csv` as the LB-100 mechanical source for
the first controlled KiCad board import under `EVT-LAYOUT-AUTHORIZED`:

- Board outline: `100.0 mm x 70.0 mm`.
- Mounting: four `2.7 mm` finished NPTH M2.5 clearance holes at
  `X5.0/Y5.0`, `X95.0/Y5.0`, `X5.0/Y65.0`, and `X95.0/Y65.0`.
- JPB1: centered FX18 stack datum at `X50.0/Y35.0`, long axis along `X`.
- MCU: central STM32H563VITx service corridor with SWD, BOOT0, RESET, and clock
  access.
- Power rails: PB_5V_OUT entry and LB_3V3 conversion near JPB1 with no-back-power
  separation from service USB.
- microSD: right-edge card access with local ESD and card-detect clearance.
- BLE: U7 at `(72,59)` with the ceramic antenna facing the `+Y` edge and the
  project-derived six-copper-layer keepout documented in
  `LB-100-e73-antenna-keepout.md`.
- Sensors: documented board axes plus quiet IMU and lux/aperture zones.
- Expansion/service: generic DNP/service keepouts while CAN1_TX_ROUTE remains
  DNP/open by default.

## Engineering Impact

- Cost impact: prototype PCB area is `70 cm²`. The outline is smaller than
  PB-100 but large enough for LQFP-100 fanout, RF keepout, storage access, and
  service connectors without using vendor-minimum DFM rules.
- Thermal impact: modest positive impact because regulator placement is kept
  near JPB1 and away from BLE and sensors. Final regulator dissipation, sleep
  current, and no-back-power behavior remain separate electrical and bench
  gates.
- Production impact: improves JLCPCB/PCBWay board-import readiness by defining
  outline, holes, connector/service access, RF keepout, sensor orientation, and
  stack datum before layout. It still does not authorize Gerbers, drills,
  pick-place, BOM/CPL, panel files, manufacturing ZIPs, fabrication packages, or
  PCBA orders.
- Field reliability: four-corner retention, edge-access storage, separated RF
  and regulator zones, serviceable SWD/BOOT/RESET, and a documented CAN1_TX_ROUTE
  DNP/open boundary reduce service damage, RF margin risk, debug dead ends, and
  accidental vehicle-CAN transmit enablement.

## Risks And Open Follow-Ups

- Final enclosure CAD or PB-100 standoff hardware can still move outline,
  mounting holes, service windows, and stack clearance.
- JPB1 uses the corrected `FX18-100P-0.8SV10` plus
  `FX18-100S-0.8SV10` 20 mm pair, four shared M2.5 stack holes, and
  20.3 +/-0.127 mm spacers. Physical fit and vibration are deferred to
  PB-BENCH-014/015 rather than treated as pre-layout evidence.
- CAN, USB, SD, clock, BLE antenna, and sensor placement/routing constraints
  remain open in the signal-integrity and safety layout model.
- The E73 manual does not publish a numeric host-PCB keepout. The implemented
  boundary is derived from its official terminal geometry and must be checked
  with the final enclosure and EVT range measurements.
- Missing optional hardware must remain a capability-unavailable state in
  firmware rather than a board-specific firmware fork.

## Alternatives

- Match LB-100 to the full PB-100 outline. Rejected for Rev.1 because it adds
  board area without improving logic-board serviceability and can put RF/storage
  features too close to high-current PB zones.
- Use PB-100 M3 holes for a shared stack. Rejected for the first prototype
  because independent M2.5 LB retention gives more freedom to tune board spacing
  and service access.
- Place BLE internally. Rejected because edge placement gives better RF margin
  and clearer copper keepout enforcement.
- Encode vehicle-specific connector positions. Rejected because architecture
  requires capability-driven hardware and configuration-based role mapping.

## Source Evidence

- `LB-100-mechanical-layout-inputs.csv`
- `LB-100-mechanical-envelope-inventory.csv`
- `LB-100-jpb1-resource-budget.csv`
- `LB-100-power-budget-precheck.md`
- `LB-100-rail-budget-closeout-precheck.csv`
- `LB-100-stm32h563-pin-binding-precheck.csv`
- `LB-100-mcu-sourcing-precheck.csv`
- `LB-100-communication-safety-precheck.csv`
- `LB-100-service-storage-sensor-precheck.csv`
- `hardware/power-board/PB-100/PB-100-b2b-interface-closeout-precheck.csv`
- `hardware/power-board/PB-100/PB-100-mechanical-layout-inputs.csv`
- `production/board-order/three_board_layout_rules.md`
- `docs/adr/ADR-0002-can-read-only-default.md`
- `docs/adr/ADR-0005-stm32h5-product-target.md`
- `docs/adr/ADR-0012-system-sleep-wake-and-parking-current.md`
- `docs/adr/ADR-0014-lb-fb-baseline-requirements.md`

## Boundary

LB-100 mechanical envelope is closed as a layout input. KiCad board import,
placement and routing are authorized. The signal-integrity and safety layout
model remains an `EVT-FAB-REVIEW` closeout item, while JLCPCB/PCBWay order state
remains `NO-GO` until `EVT-FAB-AUTHORIZED`.

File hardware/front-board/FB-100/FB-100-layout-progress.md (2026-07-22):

# FB-100 Controlled Layout Progress

Status: `EVT-LAYOUT-AUTHORIZED` — connectivity routing complete; fab review open

## Completed Milestone

- Created the deterministic `kicad/FB-100.kicad_pcb` board import from the
  frozen 44-component schematic and project-local footprints.
- Applied the reviewed 80.0 mm x 35.0 mm outline and four 2.7 mm NPTH M2.5
  holes at `(5,5)`, `(75,5)`, `(5,30)`, and `(75,30)`.
- Placed the USB-C receptacle at the X=0 service edge and kept USB ESD plus CC,
  shield, and defined-low VBUS-detect passives in the connector-side zone.
- Placed the rear/internal JFB1 FFC connector on the back side at the X=80
  cable edge and retained pins 4/5 for `USB_D_P` / `USB_D_N`.
- Applied the role-free STATUS and CH1..CH10 optical grid, SERVICE/RESET
  actuator targets, optional OLED DNP window, panel openings, and cable-bend
  review graphics.
- Added board-specific minimum clearance, track-width, and USB differential-
  pair rules in `kicad/FB-100.kicad_dru`.
- Repositioned the USB ESD/passive cluster and RGB driver support parts to
  provide manufacturable fan-out without changing the outline, optical grid,
  USB panel datum, FFC datum, or mounting holes.
- Routed every electrical connection with 457 straight segments and 48
  through vias, then added one filled GND zone per copper layer. The routing is
  stored in `kicad/FB-100-routing.csv` and remains deterministic under CI
  regeneration.
- KiCad 10.0.4 reports zero unconnected items and zero DRC violations after
  refill. A separate raw library audit accepts only the generated J1/JFB1
  transforms. Three additional GND vias bound USB reference-layer transitions.
- Locked the committed USB analytical precheck at 0.154 mm width, 0.2032 mm
  edge gap, 0.0151 mm routed skew and approximately 91.5 ohm differential on
  the selected 0.0994 mm 3313 reference spacing. Supplier field-solver
  confirmation is still required.
- Schematic parity is exact apart from H1-H4, which are board-only mechanical
  mounting holes.

## Open Layout Work

- Review JFB1 mating-side/reverse FFC orientation against the future LB-100
  placement before any prototype package is authorized.
- Submit the selected 1.6 mm/3313 stack, width and spacing to the actual PCB
  supplier impedance calculator/field solver; the analytical precheck is not
  manufacturing acceptance.
- Review the routed CC, VBUS detect-only, RGB, buttons, OLED-DNP, indicator,
  power, ground, shield and ESD return paths together with the four filled GND
  zones; revise zone keepouts if the USB/no-back-power review requires it.
- Complete enclosure, cable, assembly-orientation and supplier DFM review; the
  current KiCad DRC, courtyard and silkscreen check is clean.

## Release Boundary

This milestone is a controlled layout artifact only. It does not authorize or
create Gerbers, drill files, BOM/CPL, pick-and-place, panel files,
manufacturing ZIPs, fabrication packages, PCBA orders, production release, or
field use. FB-100 remains `EVT-LAYOUT-AUTHORIZED` and order state remains
`NO-GO` until a separate `EVT-FAB-REVIEW` closes.

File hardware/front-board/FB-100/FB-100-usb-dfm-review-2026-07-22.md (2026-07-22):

# FB-100 USB and DFM Review — 2026-07-22

Status: board geometry reviewed; supplier impedance and physical FFC fit remain open

## KiCad evidence

KiCad 10.0.4 checks the regenerated FB-100 after zone refill with:

- 44 schematic footprints plus H1-H4;
- 457 routed segments and 48 through vias;
- four GND zones, one per copper layer;
- zero unconnected items;
- zero DRC violations;
- schematic parity containing only the four board-only mounting holes.

The raw library audit contains only the intentional generated transforms for
J1 and JFB1. Their pad sets, layers and net assignments are validator-covered.

## USB routing precheck

The committed stack model is the JLCPCB-style 1.6 mm four-layer construction:

- outer copper `0.035 mm`;
- `F.Cu`/`In1.Cu` and `In2.Cu`/`B.Cu` 3313 RC57% dielectric
  `0.0994 mm`, nominal `Er=4.1`;
- inner copper `0.0152 mm`;
- `1.265 mm` FR-4 core.

The long B.Cu portion of `USB_D_P`/`USB_D_N` is `0.154 mm` wide with
`0.2032 mm` edge gap and continuous In2.Cu GND reference. Total routed lengths
are `96.9368 mm` and `96.9519 mm`, giving `0.0151 mm` skew. An IPC-style
edge-coupled microstrip precheck gives approximately `91.5 ohm` differential.
This is a regression calculation, not a supplier field-solver result.

Three return vias were added at `(2.2,17.75)`, `(11.8,3.5)` and `(66.5,5.5)`.
Together with the existing GND vias, every grouped USB layer transition has a
GND via within 4 mm. The validator locks width, gap, skew, analytical impedance
range and return-via proximity.

JLCPCB's official calculator guide confirms the 3313 nominal dielectric data
and requires the chosen stack, width and conductor spacing to be submitted to
its impedance calculator/order review. The exact manufacturing field-solver
result and tolerance therefore remain open until the actual supplier and stack
are selected:

- <https://jlcpcb.com/help/article/user-guide-to-the-jlcpcb-impedance-calculator>
- <https://jlcpcb.com/help/article/multi-layer-pcb-standard-laminated-structures>

## JFB1 orientation

The generated board explicitly places JFB1 on the back side at
`(75.2,17.5)`, rotation `-90 degrees`; its pads, paste, mask, fab, silk and
courtyard are all on back layers. Pin 1 is at `(76.47,11.75)` and pin 24 at
`(76.47,23.25)`. The LB mating connector remains top-side at `(6,35)`,
rotation `+90 degrees`, with the same electrical pin numbering.

Electrical orientation and D+/D- polarity are closed by exported-netlist and
PCB validation. Mechanical closure still requires the actual FFC contact-side
type, insertion direction, bend radius and latch access to be checked with an
LB/FB mock stack. Do not order a same-side or reverse-contact cable from the PCB
coordinates alone.

## Remaining fab-review gates

- supplier field-solver/impedance-order confirmation for the selected stack;
- physical JFB1/JFB1 cable and latch-fit inspection;
- USB shell stake and panel opening inspection against enclosure CAD;
- assembly-house DFM for edge connector soldering, bottom JFB1 access, DNP
  OLED population and five-board serialization;
- Product Owner `EVT-FAB-AUTHORIZED` approval.

No Gerber, drill, position, BOM/CPL or manufacturing package is created by
this review.

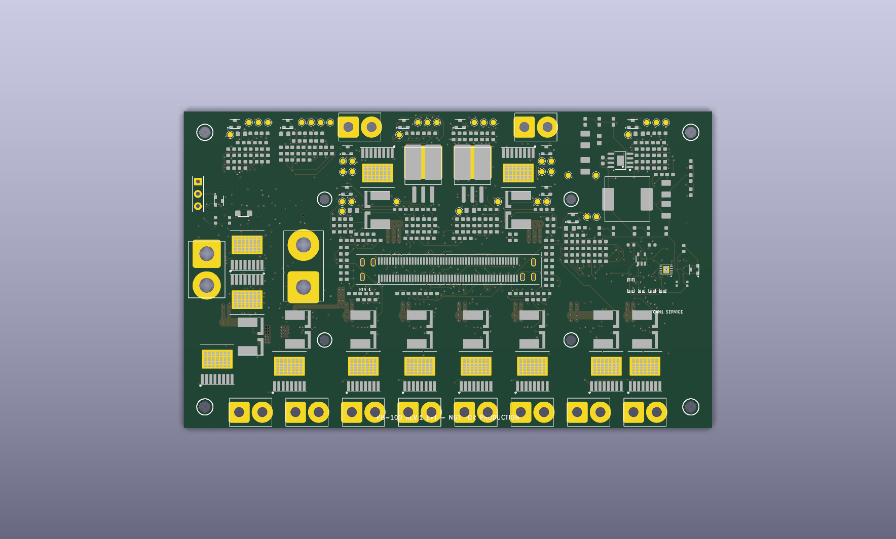
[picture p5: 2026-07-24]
docs/assets/pcb-renders/PB-100-rev1-evt-top.png

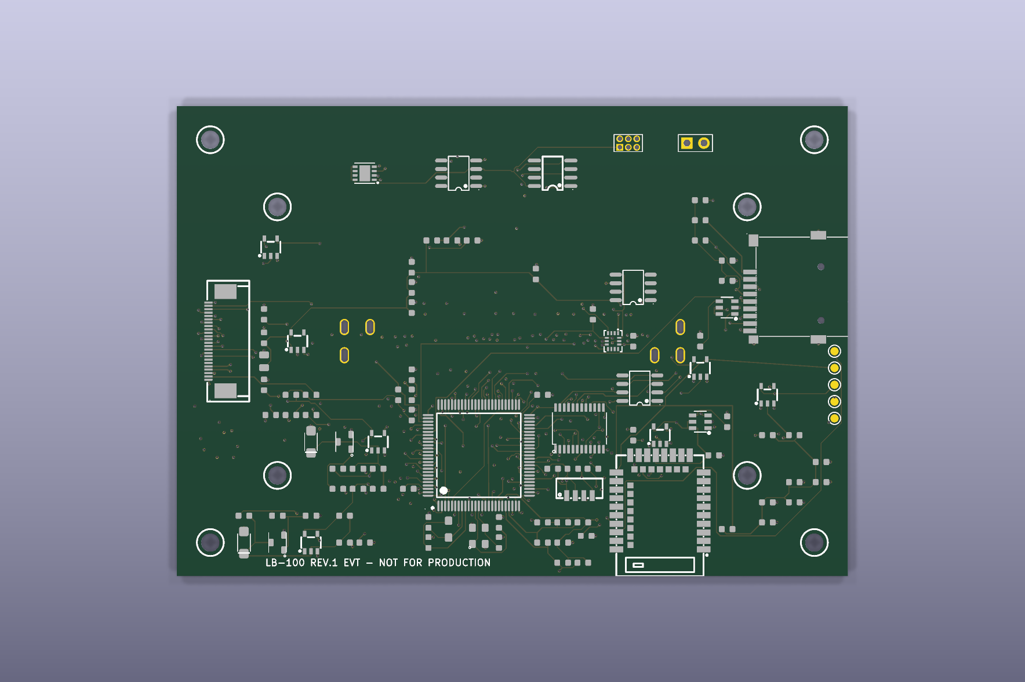
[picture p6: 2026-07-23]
docs/assets/pcb-renders/LB-100-rev1-evt-top.png

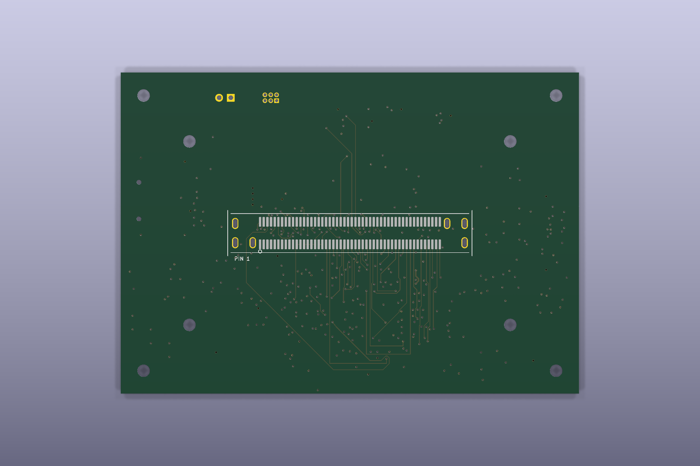
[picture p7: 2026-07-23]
docs/assets/pcb-renders/LB-100-rev1-evt-bottom.png

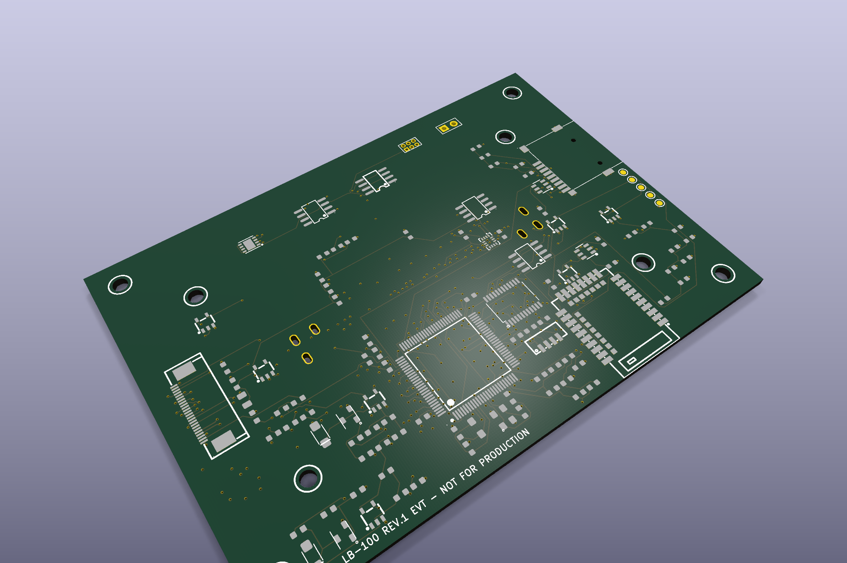
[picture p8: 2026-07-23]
docs/assets/pcb-renders/LB-100-rev1-evt-isometric.png

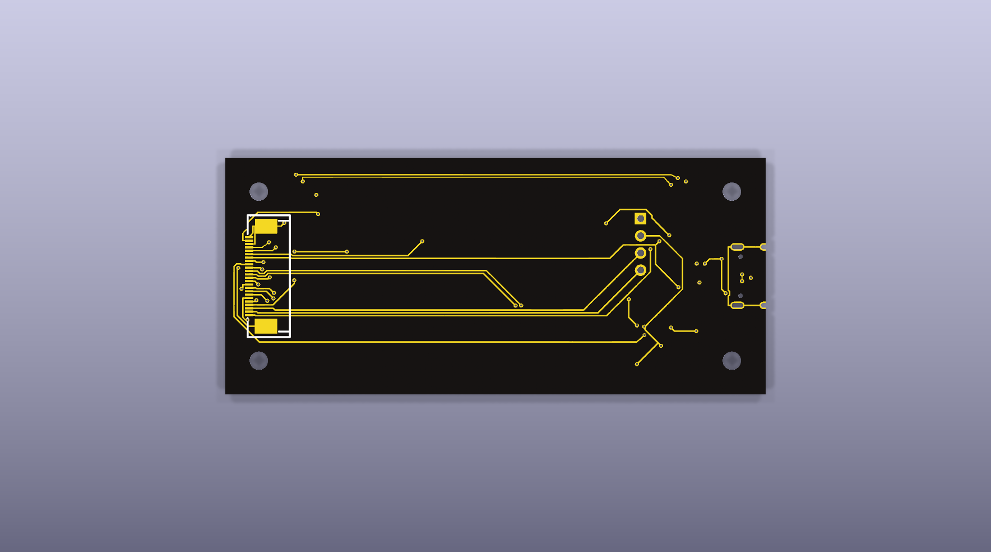
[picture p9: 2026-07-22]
docs/assets/pcb-renders/FB-100-rev1-evt-bottom.png

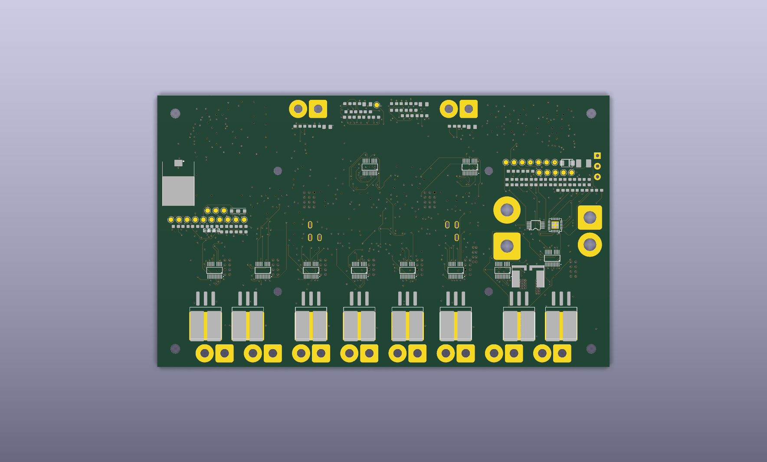
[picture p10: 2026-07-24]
docs/assets/pcb-renders/PB-100-rev1-evt-bottom.png

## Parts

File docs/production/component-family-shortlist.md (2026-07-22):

# Component Family Shortlist

Status: PB-100 critical power selections synchronized; remaining families are shortlist items

Evidence snapshot date: 2026-07-21

This document selects component families for schematic planning. It is not a
final MPN lock. LCSC/JLCPCB/PCBWay availability, assembly class, price, and
substitution risk must be rechecked before schematic freeze and before each PCBA
order.

## Selection rules

- Prefer automotive-qualified or automotive-targeted parts.
- Prefer packages suitable for factory SMD assembly.
- Prefer LCSC/JLCPCB availability where possible.
- Keep at least two viable alternatives for critical functions.
- Do not choose BGA for Rev.1 unless a later ADR accepts the tradeoff.

## Shortlist

| Function | Preferred family | Alternatives | Package direction | Notes |
|---|---|---|---|---|
| LB-100 MCU | STM32H563 | STM32H573; STM32F407 for prototypes only | LQFP-100 preferred | STM32H5 target accepted in ADR-0005 |
| Vehicle CAN transceiver | NXP TJA1051/TJA1057 | TI TCAN1042-Q1 | SOIC-8 or VSON/HVSON | CAN1 TX remains physically disabled by default |
| Expansion CAN transceiver | TI TCAN1042-Q1 | NXP TJA1051/TJA1057 | SOIC-8 or VSON/HVSON | CAN2 may transmit for bench or accessory use |
| High-side output controller | TI TPS4811-Q1 | TI TPS1211-Q1; TI TPS4810-Q1 | VSSOP/HTSSOP class | Rev.1 baseline for all PB-100 outputs with external N-MOSFETs |
| Smart high-side switch | TI TPS2HB16-Q1 | TI TPS2HB35-Q1; TI TPS1H100-Q1 | HTSSOP class | Deferred low-current alternate after ADR-0011; requires lower-clamp strategy |
| Output MOSFET | Infineon IAUT300N08S5N012ATMA2 80 V TOLL selected | Infineon IAUT300N08S5N014ATMA1 same-footprint TOLL; Nexperia BUK7J2R4-80MX 80 V LFPAK56E non-drop-in | PG-HSOF-8-1 TOLL selected with segmented paste | Generated per-class SOA and pre-layout sourcing pass; exact sheet-value promotion and physical acceptance remain gates |
| Current monitor | TPS48110 IMON for outputs; TI INA228/INA229 or INA226 for input | External analog monitor; firmware-calibrated ADC path | VSSOP/SOIC class | Per-output telemetry uses controller IMON; total input current uses dedicated shunt monitor |
| Total current shunt | Bourns CSS4J-4026R-L500F-class 0.5 mΩ four-terminal shunt | Bourns CSS4J-4026R-1L00F-class 1.0 mΩ; Isabellenhuette BVN/BAS or equivalent AEC-Q200 four-terminal family | CSS4J-4026 or reviewed power shunt | 0.5 mΩ gives 30 mV at 60 A and 1.8 W; compatible with INA228 ±40.96 mV range candidate |
| Temperature sensor | TDK NTCGS103JF103FT8-class 10 kΩ AEC-Q200 NTC | Vishay NTCS0402E3 10 kΩ AEC-Q200 150 °C class; Murata NCU18XH103D6SRB-class 10 kΩ 0603 AEC-Q200 150 °C; TI TMP117/TMP112-class digital sensor optional | 0402 preferred for NTC; SOT/DFN only for optional digital sensor | PB-100 uses PCB reference plus two power-zone thermal points; divider values and calibration remain schematic-freeze items |
| Logic buck regulator | TI LM5164-Q1 | TI LM5013-Q1; TI TPS54360B-Q1/TPS54360-Q1 | SOIC/HSOIC PowerPAD | LM5164-Q1 for 1 A 100 V rail; LM5013-Q1 preferred over 60 V family if more current is needed |
| Input active cutoff and reverse protection | TI LM74930QRGERQ1 selected | TI LM74800-Q1 family; TI LM74900-Q1 family after full cutoff/timing revalidation | VQFN-24 RGE selected | Common-source hard cutoff must remain no higher than 55 V |
| Raw-side surge cutoff MOSFET | Infineon IAUTN15S6N025ATMA1 150 V TOLL selected | 150 V automotive TOLL family; 150 V automotive LFPAK family after SOA/footprint revalidation | PG-HSOF-8-1 TOLL selected | Generated transition-energy screen passes; extracted dynamic SOA remains post-layout |
| Input reverse MOSFET | Infineon IAUT300N08S5N012ATMA2 80 V TOLL selected | Infineon IAUT300N08S5N014ATMA1 same-footprint TOLL; Nexperia BUK7J2R4-80MX 80 V LFPAK56E non-drop-in | PG-HSOF-8-1 TOLL selected with segmented paste | Generated 40 A thermal bound and pre-layout sourcing pass; plane/polygon/bus and prototype thermal acceptance remain gates |
| Legacy input TVS | Vishay SM8S33AHM3/I DNP only | Littelfuse SLD8S33A; Diodes DM8W33AQ-13; Bourns SM8S33A-Q retained as rejected comparisons | DO-218AC footprint retained unpopulated | A single TVS is not the approved load-dump solution under ADR-0018 |
| PB-100/LB-100 board-to-board connector | Hirose FX18-100P-0.8SV10 plus FX18-100S-0.8SV10 selected pair | Samtec Q Strip/high-density mezzanine class; Molex SlimStack 100-position class | 100-position 0.8 mm FX18 official 20 mm stack | Six-land footprints, MF ownership, four-spacer retention, fixture, and pre-layout mechanics are closed; live stock, factory handling, and PB-BENCH-014/015 remain release gates |
| FRAM | Fujitsu/Infineon MB85 I2C/SPI FRAM | Cypress/Infineon Excelon FRAM | SOIC/TSSOP/DFN | Configuration and black-box storage |
| RTC | Microchip MCP7940 class | NXP PCF8523/PCF8563; DS3231 class | SOIC/TSSOP/DFN/module | Prefer low-IQ SMD IC over hobby module |
| IMU | Bosch BMI270/BMI323 | TDK ICM-42688 class | LGA | Optional for Rev.1 if layout risk is high |
| Ambient light | Vishay VEML7700 | TI OPT3001 | SMD optical | Rev.1 LB placement accepted for EVT; external/window placement moves to production/Rev.2 |

## PB-100 power-path candidates

Detailed candidate MPNs for PB-100 schematic planning are tracked in
`hardware/power-board/PB-100/PB-100-power-path-candidates.csv`.

The current strategy is:

- All Rev.1 outputs: TPS48110AQDGXRQ1 high-side controller plus selected
  IAUT300N08S5N012ATMA2 80 V PG-HSOF-8-1 TOLL N-MOSFET.
- Low-current integrated smart switches: deferred alternatives only.
- Input active cutoff: LM74930QRGERQ1 with common-source external MOSFETs.
- Raw-side cutoff MOSFET: IAUTN15S6N025ATMA1 150 V TOLL selected for Q2.
- Input reverse and output MOSFET: IAUT300N08S5N012ATMA2 80 V TOLL selected,
  with IAUT300N08S5N014ATMA1 as the same-footprint controlled alternative and
  BUK7J2R4-80MX 80 V LFPAK56E as a non-drop-in production escape path.
- Input transient handling: hard cutoff at no more than 55 V; load disconnect
  is allowed. SM8S33AHM3/I remains DNP and no single-TVS branch may be credited
  as the Rev.1 load-dump solution.
- Total current shunt: 0.5 mΩ four-terminal AEC-Q200 shunt candidate for the
  0-60 A telemetry range. At 60 A the candidate produces 30 mV and about 1.8 W;
  at the 40 A board-budget point it produces 20 mV and about 0.8 W.
- Thermal telemetry: TDK `NTCGS103JF103FT8`-class 10 kΩ AEC-Q200 NTC candidate
  for `TEMP_PCB`, `TEMP_PWR_A`, and `TEMP_PWR_B`. The schematic must still
  close divider values, ADC scaling, placement, and calibration.
- Board-to-board interface: Hirose `FX18-100P-0.8SV10` plus
  `FX18-100S-0.8SV10` selected pair for `JPB1`. The official 20 mm stack,
  footprint drawings, MF ownership, LB-100 MCU binding, four-spacer retention,
  fixture, and inspection plan are closed for pre-layout work. Live stock,
  factory handling, and post-prototype continuity/vibration execution remain.

## Evidence links

- STM32H563VI is active and in volume production at ST: https://www.st.com/en/microcontrollers-microprocessors/stm32h563vi.html
- STM32H563VIT6 was listed in stock at LCSC on the snapshot date: https://www.lcsc.com/product-detail/C6937834.html
- STM32H573 family is active at ST: https://www.st.com/en/microcontrollers-microprocessors/stm32h573ii.html
- STM32H573VIT3Q had low LCSC stock on the snapshot date: https://www.lcsc.com/product-detail/C27164413.html
- NXP TJA1051T/3 variants were listed at LCSC: https://www.lcsc.com/product-detail/C58988.html
- TI TCAN1042-Q1 was listed at LCSC: https://www.lcsc.com/product-detail/can-transceivers_texas-instruments-tcan1042hgvdrbrq1_C2671243.html
- TI TPS4811-Q1 is active as an automotive high-side driver with protection and diagnostics: https://www.ti.com/product/TPS4811-Q1
- TI TPS48110AQDGXRQ1 was listed at LCSC on the snapshot date: https://www.lcsc.com/product-image/C17556513.html
- TI TPS2HB35BQPWPRQ1 was listed at LCSC on the snapshot date: https://www.lcsc.com/product-detail/power-distribution-switches_texas-instruments-tps2hb35bqpwprq1_C3230080.html
- Vishay SIDR626LDP-T1-RE3 sourcing and data-sheet evidence is retained only as
  rejected 60 V history, not as a Rev.1 assembly substitute:
  https://www.lcsc.com/product-detail/C3279576.html and
  https://www.vishay.com/docs/77277/sidr626ldp.pdf
- TI LM74930QRGERQ1 is the selected active surge-stopper controller:
  https://www.ti.com/product/LM74930-Q1/part-details/LM74930QRGERQ1
- Infineon IAUTN15S6N025ATMA1 is the selected 150 V raw-side Q2:
  https://www.infineon.com/assets/row/public/documents/10/49/infineon-iautn15s6n025-datasheet-en.pdf
- Infineon IAUTN06S5N008 is retained only as rejected 60 V TOLL history:
  https://www.infineon.com/part/IAUTN06S5N008
- Infineon IAUT300N08S5N012 is the selected 80 V automotive
  PG-HSOF-8-1 TOLL MOSFET for Q1 and Q101-Q110:
  https://www.infineon.com/part/IAUT300N08S5N012
- Infineon IAUT300N08S5N014 is the controlled same-footprint alternative:
  https://www.infineon.com/part/IAUT300N08S5N014
- Nexperia BUK7J2R4-80M is the controlled non-drop-in 80 V LFPAK56E
  alternative: https://www.nexperia.com/product/BUK7J2R4-80M
- MCC SM8S33A reference now shows EOL/obsolete status and is retained only as a
  cautionary sourcing note: https://www.mccsemi.com/products/esd-protection-and-power-tvs/tvs/SM8S33A
- Vishay SM8S HM3 AEC-Q101 DO-218AC data was checked as the active TVS class
  direction: https://www.vishay.com/docs/98647/sm8s85ahm3.pdf
- Vishay SM8S HE3 data is now treated as NFD stock-only evidence:
  https://www.vishay.com/doc/?88387=
- TI TPS2HB16-Q1 datasheet is available through LCSC: https://datasheet.lcsc.com/datasheet/pdf/5e972c8f510fd1d0477aeb85de68fc2f.pdf
- TI INA226AIDGST was listed at LCSC: https://www.lcsc.com/product-detail/current-sense-amplifiers_texas-instruments-ina226aidgst_C2653870.html
- TI INA228-Q1 supports the shunt-voltage range needed for the 0.5 mΩ current
  shunt candidate: https://www.ti.com/lit/ds/symlink/ina228-q1.pdf
- Bourns CSS4J-4026 0.5 mΩ four-terminal AEC-Q200 shunt data was checked:
  https://www.bourns.com/docs/product-datasheets/css4j-4026.pdf
- TI TMP117 data sheet was checked for optional digital board-temperature sensing: https://www.ti.com/lit/gpn/TMP117
- TDK NTCGS103JF103FT8 10 kΩ 150 °C AEC-Q200 NTC product page was checked for
  PB-100 thermal sensing: https://product.tdk.com/en/search/sensor/ntc/chip-ntc-thermistor/info?part_no=NTCGS103JF103FT8
- Vishay NTCS0402E3 0402 150 °C NTC family was checked as an alternate:
  https://www.vishay.com/en/product/29003/
- Murata NCU automotive NTC part list was checked as an alternate:
  https://www.murata.com/-/media/webrenewal/tool/library/common-pdf/static-model/component-list-ntc-2508.ashx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
- Hirose FX18-100P-0.8SV10 product page was checked for the PB-100/LB-100
  candidate plug: https://www.hirose.com/product/p/CL0579-0034-1-00
- Hirose FX18-100S-0.8SV10 product page was checked for the PB-100/LB-100
  candidate receptacle: https://www.hirose.com/product/p/CL0579-0058-0-00
- Hirose FX18 series catalog was checked for 0.8 mm pitch, 100-position, and
  power/MF-contact planning evidence:
  https://www.hirose.com/product/series/catalogdownload?category=FX18
- TI LM5164QDDATQ1 was listed at LCSC: https://www.lcsc.com/product-detail/C1850350.html
- TI LM5164-Q1 is active as a 6-100 V 1 A automotive buck regulator: https://www.ti.com/product/LM5164-Q1
- TI LM5013-Q1 is active as a 6-100 V 3.5 A automotive buck regulator: https://www.ti.com/product/LM5013-Q1
- TI TPS54360B-Q1 is active as an automotive 60 V 3.5 A buck regulator: https://www.ti.com/product/TPS54360B-Q1

## Remaining gates before schematic freeze

- Synchronize remaining passive and clamp values into value-bearing sheets.
- Carry the generated output SOA and hot-loss limits into layout and prototype
  thermal acceptance.
- Keep the generated 59.45 V transient bound below the 20 nH layout escape
  limit and confirm it in PB-BENCH-004.
- Confirm high-side controller availability through at least two suppliers.
- Confirm selected PG-HSOF-8-1 TOLL handling at actual JLCPCB/PCBWay quote;
  IAUT300N08S5N014ATMA1 and BUK7J2R4-80MX remain controlled alternatives.

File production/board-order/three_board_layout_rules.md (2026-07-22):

# Three-Board PCB Layout Rules Baseline

Status: Active
Evidence date: 2026-07-20

This baseline starts controlled PCB-layout preparation for PB-100, LB-100, and
FB-100 after schematic freeze. It does not create KiCad PCB layout files,
Gerbers, drills, pick-place files, BOM/CPL order packages, manufacturing ZIP
files, fabrication packages, or PCBA orders.

## Source Evidence

- JLCPCB PCB capabilities:
  `https://jlcpcb.com/capabilities/pcb-capabilities`.
- JLCPCB PCB assembly capabilities:
  `https://jlcpcb.com/capabilities/pcb-assembly-capabilities`.
- JLCPCB panelization and edge-clearance guidance:
  `https://jlcpcb.com/blog/pcb-panelization`.
- PCBWay manufacturing tolerances:
  `https://www.pcbway.com/pcb_prototype/PCB_Manufacturing_tolerances.html`.
- PCBWay panel requirements for assembly:
  `https://www.pcbway.com/pcb_prototype/Panel_Requirements_for_Assembly.html`.

## Conservative DRC Floor

- Default signal trace/space floor: `0.15 mm / 0.15 mm` or larger.
- Default non-BGA via floor: `0.30 mm` finished hole with `0.60 mm` pad or
  larger.
- Do not use vendor minimums as normal design values. Smaller geometry requires
  a board-specific DFM note, vendor-source evidence, and layout review approval.
- For 2 oz or heavier copper, use the applicable vendor heavy-copper
  trace/space floor and keep power-path geometry above the minimum whenever
  routing space allows.
- PB-100 high-current paths must be polygons, planes, or buses sized by
  current, temperature rise, fuse coordination, connector derating, and return
  path review. The signal DRC floor is never sufficient evidence for PB-100
  power copper.

## Assembly Baseline

- Prefer `0603` and larger passive packages for serviceability. `0402` is
  allowed only for factory-owned dense sections with sourcing and inspection
  review.
- Avoid packages smaller than `0402` in Rev.1 unless a specific footprint,
  assembly-source, inspection, and rework review is closed.
- Add global fiducials for each assembled board; add local fiducials around
  fine-pitch connectors, USB-C, dense MCU regions, and any BGA/QFN escape if
  such packages are introduced by approved requirements.
- Keep polarity, pin-1, DNP/open, and variant-population markings reviewable in
  schematic, BOM, silkscreen notes, and assembly drawings before order release.

## Mechanical And Panel Baseline

- Board outline, mounting holes, connector edge positions, cable exits, and
  enclosure keepouts must close before routing review.
- Keep stress-sensitive or tall components at least `2.0 mm` from scored or
  routed separation edges unless a board-specific mechanical review approves a
  smaller clearance.
- Keep ordinary components at least `1.0 mm` from V-score edges and at least
  `0.5 mm` from tab-routed edges unless vendor DFM review approves otherwise.
- Panelization is not a repo-generated release artifact at layout start. Final
  panel method, rails, tooling holes, fiducials, and breakaway strategy close
  during manufacturing-package review.

## Board-Specific Layout Boundaries

- PB-100: place input protection, high-current outputs, fuses, connectors,
  shunts, thermal sensors, and JPB1 only after footprint binding and mechanical
  envelope gates close. High-current copper requires a separate thermal/current
  review before board-print release.
- LB-100: place STM32H563VITx, JPB1, CAN, service/storage, BLE, sensors, and
  power rails only after footprint binding and PB/LB mezzanine stack review
  close. CAN1 remains read-only by default and `CAN1_TX_ROUTE` stays DNP/open.
- FB-100: place USB-C, ESD protection, service buttons, channel LEDs, status
  LEDs, and JFB1 only after USB-C edge, no-back-power, panel/mechanical, and
  service-access gates close.

## Output Boundary

The next allowed work follows ADR-0020. `EVT-LAYOUT-AUTHORIZED` permits
controlled KiCad board creation and routing. `EVT-FAB-REVIEW` records completed
routing while DRC, parity, safety and DFM are reviewed. Only
`EVT-FAB-AUTHORIZED` permits clearly marked EVT Gerbers, drills, BOM/CPL,
placement, assembly and limited prototype orders. `PRODUCTION-RELEASE` plus
the normal production package gates is required for production. Manufacturing outputs remain blocked
before `EVT-FAB-AUTHORIZED`; EVT outputs must never be
represented as production-ready evidence.

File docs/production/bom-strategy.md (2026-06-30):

# BOM Strategy

## Two BOMs

### Factory BOM
Everything installed by PCBWay/JLCPCB:
- MCU
- CAN transceivers
- DC/DC
- FRAM
- RTC
- IMU
- light sensor
- current sensors
- MOSFETs
- TVS/ESD/protection
- small passives

### Garage BOM
Everything installed manually:
- Deutsch connectors
- fuses
- enclosure
- gasket
- screws
- wires
- heat shrink
- harness tape
- mounting hardware

## Rule

If a part is QFN, LQFP, 0402, 0603, or otherwise annoying to solder manually, it belongs in Factory BOM.

PB-100 garage connector and fuse planning is tracked in
`hardware/power-board/PB-100/PB-100-garage-connector-fuse-plan.md`.

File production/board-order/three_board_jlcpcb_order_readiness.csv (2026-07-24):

Board | Release state | Board path | Requirements state | Schematic freeze state | KiCad schematic state | PCB layout state | Fabrication output state | Assembly output state | Order state | Active blocker count | Active blocker IDs | Blocking evidence | Next action
PB-100 | EVT-LAYOUT-AUTHORIZED | hardware/power-board/PB-100 | Frozen by ADR-0006 ADR-0016 ADR-0018 and unified EVT process ADR-0020 | Open | Controlled value-bearing 414-part schematic import binds LM74930QRGERQ1 active cutoff IAUTN15S6N025ATMA1 150V Q2 exact 80V TOLL Q1/Q101-Q110 and DNP legacy D1 plus the ADR-0021 protected FOG entry | Controlled eight-layer PB-100.kicad_pcb places 414 footprint-bound schematic parts plus eight mounting holes and contains 5049 segments 874 vias and 38 zones; refill DRC has 36 open connections and no new short crossing clearance edge drill or keepout errors | No fabrication outputs | No assembly outputs | NO-GO | 1 | PBREL-007 | ADR-0020 permits controlled layout and ADR-0021 assigns primary FOG transient protection to PB-100 but PB-100-pcb-layout-start-checklist.csv keeps final EVT schematic DRC footprint binding mechanical envelope residual connectivity 40A electrothermal clamp-loop DFM safety and segregated five-board package gates open; PBREL-007 remains Conditional only for PRODUCTION-RELEASE | Close the 36 remaining connections then complete rail CAN 40A electrothermal supplier DFM and Product Owner review before EVT-FAB-REVIEW; do not generate JLCPCB/PCBWay outputs now
LB-100 | EVT-FAB-AUTHORIZED | hardware/logic-board/LB-100 | Frozen by ADR-0014 and amended by accepted ADR-0020 and ADR-0021 | Closed | Reviewed 104-component 199-net footprint-bound KiCad schematic with typed IC pins ADC reference grounding independent protected PA8/PA9 fog inputs digital VBUS detection direct LTC3212 drive back-power-safe sensors switched-rail Ioff E73 UART/reset isolation and five-pad module recovery access | Connectivity-complete six-layer EVT routing in kicad/LB-100.kicad_pcb places 104 footprint-bound parts and uses 2274 segments and 409 vias of the standard through type; four GND zones and the exact six-copper-layer E73 keepout are present; refill DRC has zero errors and zero unconnected items with only validator-locked non-electrical warnings | Segregated LB-only EVT Gerber and PTH/NPTH drill package plus previews; not production | No assembly outputs; bare-PCB EVT release only | EVT-READY | 0 |  | LB-100-pcb-layout-start-checklist.csv and LB-100-evt-fab-review-checklist.csv record closed routing DRC footprint binding mechanical envelope USB FFC storage and review gates; Product Owner authorized one five-board LB-only EVT batch while PB and aggregate order remain NO-GO | Run supplier automated DFM select JLC06161H-3313 request 90 ohm USB control and stop before payment on any unreviewed stack drill outline impedance or geometry substitution
FB-100 | EVT-LAYOUT-AUTHORIZED | hardware/front-board/FB-100 | Frozen by ADR-0014 and EVT process ADR-0020 | Closed | Reviewed 44-component 46-net footprint-bound KiCad schematic with USB-C ESD no-back-power R13/R14/C1 defined-low VBUS detect direct one-wire RGB buttons and DNP OLED | Connectivity-complete EVT routing in kicad/FB-100.kicad_pcb places 44 footprint-bound parts and uses 457 segments 48 vias and four GND zones; source DRC reports 7 open connections before refill while required refill DRC has zero violations and zero unconnected items; width gap 0.0151 mm skew analytical impedance and USB return-via proximity are validator-covered | No fabrication outputs | No assembly outputs | NO-GO | 0 |  | FB-100-pcb-layout-start-checklist.csv records closed schematic footprint binding mechanical envelope and USB/no-back-power gates; FB-100-usb-dfm-review-2026-07-22.md and tools/validate_fb100_layout.py record the clean DRC stack model approximately 91.5 ohm analytical precheck and exact JFB1 transform; supplier field-solver physical FFC orientation enclosure and assembly DFM remain open | Close supplier impedance confirmation physical JFB1 cable/latch fit optional FOG-button enclosure and assembly/package review before EVT-FAB-AUTHORIZED; do not generate JLCPCB/PCBWay outputs now

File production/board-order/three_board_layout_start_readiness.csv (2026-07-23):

Board | Release state | Freeze state | Layout planning state | KiCad board import state | Footprint binding state | Mechanical envelope state | Assembly/DFM baseline | Fabrication/assembly output state | Order state | Active blocker count | Active blocker IDs | Blocking evidence | Next action
PB-100 | EVT-LAYOUT-AUTHORIZED | Open | READY | READY | CLOSED - LM74930-Q1 RGE IAUT300N08S5N012ATMA2 Q1 IAUTN15S6N025ATMA1 Q2 TOLL protected FOG entry pin/pad maps segmented paste and corrected FX18 pair are reviewed | CLOSED - PB-100 mechanical inventory has 0 open items; corrected P-SV10 plus S-SV10 pair four spacers MF/TH lands pin-1 fixture and inspection evidence are reviewed | READY - production/board-order/three_board_layout_rules.md | No fabrication outputs and no assembly outputs | NO-GO | 1 | PBREL-007 | Controlled partial PB-100.kicad_pcb places 33 footprint-bound schematic parts and eight holes and routes nine CAN1 safety nets plus the protected three-wire FOG entry with 110 segments and 14 vias; 46 missing footprints six U1 parity findings 127 connections and all power routing remain explicit EVT-FAB blockers while PBREL-007 remains production-only; PB-100-pcb-layout-start-checklist.csv controls manufacturing artifacts | Promote the missing value-bearing power-stage parts and terminals then re-import place and route the full Rev.1 EVT with test points alternative DNP sites replaceable gate resistors isolation links safe-off controls and EVT serial field
LB-100 | EVT-FAB-AUTHORIZED | Closed | READY | READY | CLOSED - all 104 value-bearing schematic components have reviewed project-local Footprint properties; TP1-TP5 expose E73 SWDIO SWDCLK reset switched target reference and GND; PA8/PA9 receive independent series RC clamp and Schmitt-buffer fog inputs with mutually exclusive DNP 12V paths while PB owns primary cable-entry protection; U15-U17 isolate E73 UART/reset while off; ERC uses electrical pin types and ADR-0015 keeps the CAN1 physical layer off LB-100 | CLOSED - LB-100 mechanical inventory has 0 open items; corrected P-SV10 plus S-SV10 pair four spacers MF/TH lands pin-1 fixture and inspection evidence are reviewed | READY - production/board-order/three_board_layout_rules.md | Segregated LB-only EVT manufacturing artifact contains Gerber drill review notes and previews; no assembly outputs and not for production | EVT-READY | 0 |  | Controlled six-layer LB-100.kicad_pcb contains 2274 segments 409 standard through vias four GND zones an exact six-copper-layer E73 keepout and zero refill DRC errors or unconnected items; LB-100-pcb-layout-start-checklist.csv and the EVT fab review control the limited manufacturing artifacts while PB and aggregate ordering remain NO-GO | Upload only the LB package select JLC06161H-3313 request 90 ohm USB control run supplier DFM and stop before payment on any unreviewed substitution
FB-100 | EVT-LAYOUT-AUTHORIZED | Closed | READY | READY | CLOSED - all 44 value-bearing schematic components have reviewed project-local Footprint properties including USB-C ESD defined-low VBUS detect RGB driver buttons LEDs FPC and DNP OLED header | CLOSED - FB-100 mechanical envelope inputs are reviewed with 0 open items | READY - production/board-order/three_board_layout_rules.md | No fabrication outputs and no assembly outputs | NO-GO | 0 |  | Controlled FB-100.kicad_pcb contains 457 segments 48 vias and four GND zones; source-board DRC has 7 open GND connections before refill and required zone-refill DRC has zero violations and unconnected findings; stack geometry USB skew analytical impedance and return-via proximity are validator-covered while supplier impedance physical JFB1 fit and assembly DFM remain EVT-FAB blockers; FB-100-pcb-layout-start-checklist.csv controls manufacturing artifacts | Confirm USB in the supplier field solver and close physical JFB1 cable/latch orientation optional FOG-button enclosure fit and assembly DFM without changing the outline before EVT-FAB-REVIEW

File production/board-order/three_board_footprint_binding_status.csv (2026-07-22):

Board | Inventory | Evidence source | KiCad symbol state | Open footprint items | Package sources identified | Board import state | Blocked action
PB-100 | hardware/power-board/PB-100/PB-100-footprint-binding-inventory.csv | PB-100-kicad-footprint-plan.csv, PB-100-symbol-mpn-readiness.csv, PB-100-symbol-pin-evidence.csv, PB-100-symbol-footprint-pad-map.csv, PB-100-footprint-binding-progress.csv, PB-100-footprint-binding-closeout-2026-07-20.md, PB-100-footprint-binding-closeout-2026-07-20-power-telemetry.md, PB-100-footprint-binding-closeout-2026-07-20-mosfet-packages.md, PB-100-fx18-paired-stack-closeout.md, ADR-0021, and kicad/lib/PB100.pretty | All required PB footprint classes have local reviewed or source-identified package evidence including LM74930-Q1 RGE Q2 TOLL CAN1 protected FOG cable entry and the corrected six-land P-SV10 plus S-SV10 FX18 pair; controlled promotion continues during EVT layout | 0 | 23 | READY | Continue PB-100.kicad_pcb under EVT-LAYOUT-AUTHORIZED; manufacturing waits for EVT-FAB-AUTHORIZED
LB-100 | hardware/logic-board/LB-100/LB-100-footprint-binding-inventory.csv | LB-100-component-sourcing-precheck.csv, LB-100-mcu-sourcing-precheck.csv, LB-100-footprint-binding-progress.csv, LB-100-e73-recovery-interface.md, PB-100-fx18-paired-stack-closeout.md, docs/adr/ADR-0015-can1-physical-layer-board-ownership.md, docs/adr/ADR-0020-platform-evt-development-and-reference-loads.md, docs/adr/ADR-0021-fog-switch-common-and-protection-ownership.md, and kicad/lib/LB100.pretty | All required LB footprint classes are reviewed and bound to the 104 value-bearing schematic components including U14 U15-U19 D19-D20 Q18/Q19 TP1-TP5 and the dual-input secondary conditioning networks; the five test pads provide E73 module recovery access and are non-assembly; PB owns D_FOG1 primary protection while FX18 has four GND MF circuits and six official-geometry TH lands and ADR-0015 keeps the CAN1 physical layer off LB-100 | 0 | 23 | READY | Continue routing LB-100 under EVT-LAYOUT-AUTHORIZED; manufacturing waits for EVT-FAB-AUTHORIZED
FB-100 | hardware/front-board/FB-100/FB-100-footprint-binding-inventory.csv | FB-100-component-sourcing-precheck.csv; FB-100-schematic-review-closeout.md; kicad/lib/FB100.pretty | Project-local FB100.pretty footprints are reviewed and bound to all 44 value-bearing schematic components including the R14 USB pulldown RGB driver and DNP OLED header; no empty Footprint properties remain | 0 | 14 | READY | Controlled FB-100 board import may start; fabrication assembly and order outputs remain unauthorized until layout review closes

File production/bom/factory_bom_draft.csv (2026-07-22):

Subsystem | Item | Suggested part/class | Package/assembly | Qty | Assembly | Priority | Notes
Logic | MCU | STM32H563VIT6 preferred; STM32H573VIT6 security alternate; STM32H563RGT6 downscope fallback requiring review | LQFP-100 preferred | 1 | Factory | Core | Product target accepted in ADR-0005; sourced in LB-100-mcu-sourcing-precheck.csv
Logic | 3V3 regulator | XC6220B331MR-G preferred; AMS1117-3.3 fallback only if thermal/dropout review accepts | SOT-25/SOT-223 class | 1 | Factory | Core | LB_3V3_MAIN_REG source evidence in LB-100-component-sourcing-precheck.csv
Logic | UI I/O expander | TCA9539QPWRQ1 preferred; PCA9539-Q1 class alternate after pin review | TSSOP-24 | 1 | Factory | Core | Automotive-qualified role-free front-panel I/O; C201627 sourcing and footprint are reviewed
Logic | Peripheral load switch | TPS22918TDBVRQ1 class preferred; TPS22919-Q1 reviewed family alternate | SOT-23-6 | 2 | Factory | Core | U_SW_BLE and U_SW_SD isolate optional service domains; exact orderable suffix is rechecked at release
Logic | HSE crystal | Automotive 8 MHz 3225 four-pad crystal class | 3225 four-pad | 1 | Factory | Core | Exact AEC-Q200 MPN load capacitance and startup margin close before production release
Logic | LSE crystal | Automotive 32.768 kHz 3215 two-pad crystal class | 3215 two-pad | 1 | Factory | Core | Exact AEC-Q200 MPN load capacitance and startup margin close before production release
Power | CAN1 PB physical layer | NXP TJA1051TK/3/1J preferred; TJA1057GTK/3Z same-class alternate; TCAN1042HGV-Q1 reviewed non-drop-in alternate | HVSON-8-EP on PB-100 | 1 | Factory | Core | ADR-0015 Accepted candidate A; PB owns CAN1 transceiver and harness physical layer while LB owns FDCAN protocol and read-only policy
Logic | CAN2 transceiver | NXP TJA1051T/1J preferred; TJA1051T/CM or TJA1051TK/3 alternate | SOIC-8/HVSON class | 1 | Factory | Should | Expansion CAN may transmit; source evidence in LB-100-component-sourcing-precheck.csv
Logic | BLE module | E73-2G4M08S1C preferred; MS88SF3 nRF52840 alternate | Module | 1 | Factory | Should | UART/SPI control remains configuration-owned
Logic | BLE powered-off isolation | SN74LVC1G125QDBVRQ1 preferred; 74LVC1G125-Q100 or SN74LVC1G125B-Q1 controlled alternates | SOT-23-5 | 3 | Factory | Core | U15-U17 powered from RADIO_SENSOR_3V3 isolate both UART directions and reset with Ioff
Logic | microSD socket | SOFNG TF-015 preferred; LCK_TF_113H1509WLG alternate | SMD | 1 | Factory | Core | Logs/config; source evidence in LB-100-component-sourcing-precheck.csv
Logic | RTC | DS3231MZ preferred; DS3231M+TRL alternate | SMD | 1 | Factory | Should | Log timestamps
Logic | FRAM | FM24CL64B-GTR preferred; MB85RC256-class alternate | SMD | 1 | Factory | Core | Black box/settings
Logic | IMU | BMI270 preferred; BMA456 alternate | LGA | 1 | Factory | Should | Shock/tilt/vibration
Logic | Lux sensor | VEML7700 preferred; BH1750 alternate | SMD | 1 | Factory | Core | Fog logic
Logic | Temp sensor | TDK NTCGS103JF103FT8-class 10k 150C AEC-Q200 NTC default; TMP117/TMP112-class digital optional | 0402 SMD | 3 | Factory | Core | PB-100 PCB temp plus two power-zone temp points; divider calibration TBD
Power | Current sensor | TPS48110 IMON per output; INA228/INA229 or INA226-class total input monitor | VSSOP/SOIC class | 11 | Factory | Core | Ten output telemetry paths plus one total input current monitor
Power | Input current shunt | Bourns CSS4J-4026R-L500F-class 0.5mΩ four-terminal automotive shunt | CSS4J-4026 or reviewed power shunt package | 1 | Factory | Core | 0.5mΩ gives 30mV at 60A and 1.8W; package assembly and Kelvin routing remain freeze checks
Power | High-side switch/controller | TPS48110AQDGXRQ1-class for all Rev.1 outputs | VSSOP/HTSSOP | 10 | Factory | Core | Integrated smart switches deferred by ADR-0011
Power | MOSFET | IAUT300N08S5N012ATMA2 selected; IAUT300N08S5N014ATMA1 same-footprint alternate; BUK7J2R4-80MX LFPAK56E non-drop-in alternate | PG-HSOF-8-1 TOLL; tape/reel MSL1; segmented paste | 10 | Factory | Core | Q101-Q110 pre-layout SOA and class values pass; preserve 125C case ceiling and repeat quote/DFM/FAI before production
Power | Input reverse MOSFET | IAUT300N08S5N012ATMA2 selected; IAUT300N08S5N014ATMA1 same-footprint alternate; BUK7J2R4-80MX LFPAK56E non-drop-in alternate | PG-HSOF-8-1 TOLL; tape/reel MSL1; segmented paste | 1 | Factory | Core | Q1 hot bound is 4.032W at 40A; passive PCB copper plus enclosure path must be <=6.20K/W at 125C ambient and verified by PB-BENCH-010
Power | Input surge cutoff MOSFET | IAUTN15S6N025ATMA1 selected 150V TOLL; alternate requires separate SOA and gate-charge review | PG-HSOF-8-1 TOLL; tape/reel; segmented paste | 1 | Factory | Core | Q2 is the raw-side LM74930-Q1 HGATE cutoff FET; extract loop overshoot and dynamic SOA before prototype fabrication
Power | Legacy TVS footprint | Vishay SM8S33AHM3/I DNP legacy branch | DO-218AC with polarity marking | 1 DNP | Factory | DNP | Not approved as the load-dump energy sink; retain only for traceability and do not populate without a new ADR
Power | Active surge and reverse protection | LM74930QRGERQ1 selected; LM74930-Q1 family alternate suffixes require pin/package review | VQFN-24 RGE 4x4mm with isolated RTN exposed pad | 1 | Factory | Core | Hard OV cutoff is 48.99-54.89V; load disconnection during load dump is permitted; common-source Q2/Q1 topology
Power | LM74930 VS energy storage | CGA6N3X7R2A225M230AE selected 2.2uF 100V X7R AEC-Q200 soft termination; alternate only after DC-bias and temperature proof | EIA 1210 | 1 | Factory | Core | CVS1 must retain at least 1uF effective capacitance at the 56V VS clamp and temperature; 100nF is not an acceptable VS storage value
Power | DC/DC | LM5164QDDATQ1 default; LM5013-Q1 high-current 100V alternate; TPS54360B-Q1 conditional 60V alternate | SOIC/HSOIC PowerPAD | 1 | Factory | Core | Logic power current and TVS margin decide final family
Power | Buck inductor | Automotive shielded power inductor class | TBD after regulator design | 1 | Factory | Core | Value saturation current and heating close with LM5164-Q1 design
Power | PB-100/LB-100 board-to-board connector | Hirose FX18-100P-0.8SV10 CL0579-0034-1-00 plus FX18-100S-0.8SV10 CL0579-0058-0-00 | 100 signal positions plus four GND MF circuits and six plated TH lands | 1 pair | Factory | Core | Official P-SV10 plus S-SV10 pair gives the required 20 mm stack; use four 20.3 +/-0.127 mm M2.5 spacers and execute PB-BENCH-014/015 before motorcycle power or production
Power | Board identity resistor network | Precision resistor divider class | 0603/0805 | 1 | Factory | Should | PB_ID_ADC fallback board revision identity
Power | Test points | Generic bring-up and telemetry test points | PCB pads or SMT test points | TBD | Factory | Should | Exact count from schematic review before layout
Power | CAN1 TX disable hardware | JP_CAN1 and JP_CAN1_NORMAL DNP/open links plus SN74LVC1G125-Q1-class gate | Two 0603 DNP/open links plus SOT-23-5 DBV gate | 1 set | Factory | Core | CAN1_TX_DISABLE production boundary: no default-populated vehicle-CAN TX path; both hardware actions require a future ADR
Power | CAN1 safety resistor network | AEC-Q200 1% resistor class | 0402 | 5 | Factory | Core | R_CAN1_OE 47k R_CAN1_TX_BIAS 47k R_CAN1_STATUS_SER 1k R_CAN1_STATUS_PULL 100k and R_CAN1_SILENT 47k are physical schematic components
Power | CAN1 bus protection and termination | TI ESD2CANFD24QDBZRQ1 preferred; Nexperia PESD2CANFD24V-T alternate; 120R termination DNP | SOT-23-3 plus 0603 DNP | 1 set | Factory | Core | PB-owned ESD at CAN harness entry; optional termination remains DNP until vehicle topology review
Power | CAN1 transceiver decoupling | 100nF 50V X7R AEC-Q200 class | 0402 | 2 | Factory | Core | One capacitor each on PB_5V_OUT VCC and LB_3V3_IO VIO close to U_CAN1_PHY
Comms | LIN transceiver | TJA1021T/20/CM preferred DNP reserve; automotive LIN alternate by review | SOIC-8 class | 1 | Factory | Future | Footprint can be DNP; source evidence in LB-100-component-sourcing-precheck.csv
Comms | RS485 transceiver | SP3485EN-L/TR preferred DNP reserve; MAX3485ESA alternate | SOIC-8 class | 1 | Factory | Future | Footprint can be DNP; source evidence in LB-100-component-sourcing-precheck.csv
Front | USB-C service connector | USB4105-GF-A preferred; TYPE-C-31-M-12 alternate | USB-C receptacle SMD | 1 | Factory | Core | FB-100 device-only service connector; no system-rail back-power
Front | USB ESD protection | USBLC6-2SC6 preferred; TPD2EUSB30ADRTR alternate | SOT-23-6/USON class | 1 | Factory | Core | Protect USB_D_P/USB_D_N at FB-100 connector
Front | Status RGB LED | Everlight 19-237/R6GHBHC-A01/2T common-anode class preferred | SMD-4P 1.6x1.6 mm | 1 | Factory | Should | Status-only indicator driven by LTC3212; no accessory role mapping
Front | RGB status driver | LTC3212EDDB#TRPBF; protocol-compatible alternate still requires qualification | DFN-12-1EP 2x3 mm | 1 | Factory | Should | One-wire RGB control preserves JFB1 contract; C684295 is out of stock so consignment or alternate qualification is required before production
Front | Channel indicator LEDs | JLCPCB discrete 0805 indication class | 0805 SMD LED | 10 | Factory | Core | Labels remain OUT1..OUT10 role-free; each path uses a reviewed 1k current limiter below 2 mA at 3.3 V
Front | FPC connector | AFC07-S24ECA-00 preferred; FPC-05F-24PH20 alternate | 24-pin 0.5 mm FPC/FFC connector | 1 | Factory | Core | JFB1 front-panel cable interface
Front | Service/reset buttons | Panasonic EVPBB4A9B000 preferred; XKB TS-1187A variants alternate | SMD tactile switch | 2 | Factory | Core | Active-low SERVICE and RESET controls
Front | Optional OLED display | Generic 1x4 I2C OLED module header DNP; QG-2864KLBEG01 or N091-2832TSWFG02-H14 direct-solder display only by variant review | 1x4 2.54 mm header | 0-1 | Factory | Future | DNP by default; module height window pin order and keep-out require layout review
Front | LED/button/USB passives | 1k LED resistors 5.1k USB-C Rd resistors R13 3.9k/R14 15k VBUS detect network and reviewed 0603/0805 capacitors | 0603/0805 class | Defined by FB-100 schematic | Factory | Core | Exact values and footprints are present in the reviewed value-bearing FB-100 schematic
Power | Output flyback clamp | STPS40170CGY-TR selected; STPS40150CGY-TR and V40PW15C-M3/I controlled automotive alternatives | D2PAK common-cathode; tape/reel; both anodes tied to GND | 10 | Factory | Core | DCL101-DCL110 cathode to OUTn_LOAD; populated local generic clamp; repeat voltage/current/thermal and footprint review for any alternate
Power | Fog cable-entry protection | ESD2CANFD24DBZRQ1; R_FOG_GND zero-ohm default; nanoASMDC010F and R_FOG_12V DNP | SOT-23-3 0603 and 1206 | 1 dual-line entry | Factory | Core | PB-100 owns primary protection; default links SW_COMMON to GND; measured active-high variant removes R_FOG_GND and fits the mutually exclusive SW_12V_FUSED path
Logic | Dual fog input conditioning | two SN74LVC1G17QDBVRQ1; two BZT52H-B4V3-Q; AEC-Q200 4.7k/47k/47nF network | SOT-23-5 SOD123F and 0603 | 2 channels | Factory | Core | LB-100 owns independent secondary conditioning; R24/R25/R28/R29/Q18/Q19 are DNP unless offline measurement selects the mutually exclusive protected 12V variant
Logic | Fog 12V input option | BC847BQ-7-F plus 47k base and 100k base-emitter resistors | SOT-23-3 plus 0603 | 2 channels DNP | Factory | Should | Populate only when the measured switch state table proves a fused 12V active-high output; DNP R23/R27 in that variant

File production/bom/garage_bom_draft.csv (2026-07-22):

Category | Item | Suggested spec | Qty | Buy/Install | Priority | Notes
Protection | Littelfuse MAXI fuse holder | MAXI 152 or MAH sealed inline 50A class | 1 | Garage | Core | Install near battery per ADR-0008; select holder variant with 50A continuous margin and matching cable seals
Protection | MAXI fuses | 50A | 2 | Garage | Core | One spare
Connectors | Battery input connector | Ring-lug battery lead plus MAXI holder then high-current sealed harness entry or serviceable gland TBD | 1 | Garage | Core | Do not use DT or DTP for 50A input path; candidate wire 6mm2 / 10AWG or larger until derating review closes
Connectors | Deutsch DTP 2-pin sets | OUT1/OUT2 high-current outputs with size 12 25A contact class | 2 | Garage | Core | DTP class for 15A/20A fuse outputs; final contacts seals boots backshells and crimp tool pending
Connectors | Deutsch DT 2-pin sets | OUT3-OUT10 outputs with size 16 13A contact class | 8 | Garage | Core | DT class for 5A/10A fuse outputs only; move any future higher-fuse output to DTP by review
Connectors | Deutsch output connector sets | DTP class for OUT1/OUT2 and DT class for OUT3-OUT10 | 10 | Garage | Core | Aggregate PB-100 output connector BOM mapping row
Connectors | Deutsch DTM 4-pin sets | CAN/service | 2 | Garage | Core | CAN/inputs
Connectors | Deutsch DTM 8-pin set | External inputs | 1 | Garage | Should | Buttons/ADC/pulse
Connectors | Deutsch DTM 3-pin fog-switch set | TE DTM04-3P plus DTM06-3S with WM-3P WM-3S and matched size-20 contacts | 1 | Garage | Core | Pin 1 SW_COMMON pin 2 FOG_A_SW_IN pin 3 FOG_B_SW_IN; dry-contact common goes to GND and measured active-high common goes to SW_12V_FUSED; do not assign wire colors or finalize loom before offline switch measurement
Tooling | Deutsch solid-contact crimp tool | HDT-48-00-class tool for size 12 size 16 and size 20 solid contacts | 1 | Garage | Core | Required before ordering partial DTP DT DTM kits; insertion/removal tool remains separate
Fuses | Mini/ATO blade fuses | 5/10/15/20A kit | 1 | Garage | Core | Per channel
Fuses | Per-output fuse holders | MINI/ATO blade holder or enclosure fuse block class | 10 | Garage | Core | Final holder style depends on enclosure
Wire | Automotive wire red/black | 6 mm2 / 10 AWG or larger after derating | 2 | Garage | Core | Battery input and main fuse path
Wire | Automotive wire | 2.5-4 mm2 / 14-12 AWG after derating | 5 | Garage | Core | High-load DTP outputs and medium DT outputs as contact range allows
Wire | Automotive wire | 0.5-1.0 mm2 / 20-18 AWG | 5 | Garage | Core | Signals/CAN only
Harness | Double fog-switch measurement record | Offline continuity resistance diode-mode and state table | 1 | Garage | Core | Required before final DTM pin crimp or external loom energization; button colors and contact electronics are currently unverified
Harness | Tesa cloth tape | Automotive harness tape | 1 | Garage | Core | User already has analog
Harness | Adhesive heat shrink | Assorted | 1 | Garage | Core | Harness sealing
Harness | FB-100 front-panel FFC cable | 24-pin FFC cable matching selected 0.5 mm JFB1 connector | 1 | Garage | Should | Garage-installed service/display cable; exact length and orientation close with enclosure
Mechanical | Enclosure | ASA/PETG printed or machined | 1 | Garage | Core | Final CAD pending
Mechanical | FB-100 front-panel mounting | 80 mm x 35 mm prototype faceplate standoffs light-pipe/window and button actuator hardware | 1 | Garage | Should | Mechanical envelope captured in FB-100-mechanical-envelope-precheck.csv; final CAD pending
Mechanical | Silicone gasket | 2 mm sheet | 1 | Garage | Core | Lid seal
Mechanical | Stainless screws | M3 assorted | 1 | Garage | Core | PCB/lid
Mechanical | Mounting hardware | Rubber isolators/clips | 1 | Garage | Should | Motorcycle mounting

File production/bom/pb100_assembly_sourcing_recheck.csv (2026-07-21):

Symbol key | Assembly owner | Preferred MPN or class | Recheck status | Recheck source | Alternate coverage | Factory action | Garage action | Freeze dependency
HS_CTRL | Factory | TPS48110AQDGXRQ1 | JLC C17556513 stock rechecked 2026-07-20 from 2026-07-16 baseline but PCBWay and value lock remain open | JLCPCB Extended plus authorized distributor stock plus PCBWay assembly | Alternates from symbol readiness must remain available | Verify package assembly class and reel availability | N/A | Close sourcing recheck before schematic freeze
OUT_FET | Factory | IAUT300N08S5N012ATMA2 selected 80V TOLL | Active/preferred through at least 2038; tape/reel MSL1; prelayout source route closed 2026-07-21 without a live-stock claim | Infineon evidence plus authorized reel and JLC global/preorder/consignment or PCBWay kitted/consigned assembly | Alternates: IAUT300N08S5N014ATMA1 same-footprint TOLL and BUK7J2R4-80MX LFPAK56E non-drop-in | Recheck order-date lifecycle reel quote stencil voiding DFM and FAI | N/A | None for PBREL pre-layout; actual quote and production release evidence remain later gates
OUT2_ESCAPE_FET | Factory | IAUT300N08S5N012ATMA2 selected 80V TOLL | Generated SOA/fuse envelope passes; active/preferred manufacturer status reviewed 2026-07-21 | Infineon data sheet plus PB-100-output-soa-evidence.csv and consigned/preorder assembly route | Alternates: IAUT300N08S5N014ATMA1 same-footprint TOLL and BUK7J2R4-80MX LFPAK56E non-drop-in | Measure startup gate waveform and temperature; recheck order quote and FAI | N/A | None for PBREL pre-layout; physical load test remains post-prototype
INPUT_IDEAL_DIODE | Factory | LM74930QRGERQ1 selected | TI active automotive component and RGE package rechecked 2026-07-21; live order-date stock and assembler quote remain open | Authorized distributor reel plus JLC global/preorder/consignment or PCBWay kitted/consigned assembly | LM74930-Q1 orderable suffix alternatives require pin/package review | Verify RGE exposed-pad isolation stencil voiding AOI and FAI | N/A | None for PBREL pre-layout; quote DFM and prototype qualification remain later gates
INPUT_CONNECTOR | Garage | Ring-lug battery lead plus MAXI holder then high-current sealed harness entry or serviceable gland TBD | Garage class narrowed 2026-07-17 and MAXI kit candidates rechecked 2026-07-20 but derating recheck before lock | PB-100-garage-purchase-kit-candidates.csv plus Littelfuse catalog evidence plus harness supplier | Alternate 50A sealed connector or gland families retained | N/A | Verify 50A path 6 mm2 / 10 AWG wire gauge cable seal lug crimp tooling strain relief install distance and serviceability | Close garage connector derating before schematic freeze
INPUT_REVERSE_FET | Factory | IAUT300N08S5N012ATMA2 selected 80V TOLL | Active/preferred status and 40A prelayout thermal bound reviewed 2026-07-21 | Infineon data sheet plus PB-100-input-q1-evidence.csv and consigned/preorder assembly route | Alternates: IAUT300N08S5N014ATMA1 same-footprint TOLL and BUK7J2R4-80MX LFPAK56E non-drop-in | Recheck passive copper/enclosure path final polygon quote solder-void FAI and PB-BENCH-010 | N/A | None for PBREL pre-layout; <=6.20K/W full path and physical validation remain later gates
INPUT_SURGE_FET | Factory | IAUTN15S6N025ATMA1 selected 150V TOLL | Infineon automotive data sheet 48-corner rise-time/thermal/SOA model and 7.200W hot conduction bound reviewed 2026-07-21 | Infineon evidence plus PB-100-surge-stopper-evidence.csv PB-100-input-q2-evidence.csv and consigned/preorder assembly route | Alternates require 150V class dynamic SOA hot RDS gate-charge and footprint review | Recheck order-date lifecycle reel quote loop extraction solder-void FAI and PB-BENCH-004 | N/A | Qualified maximum-bound 101V/40A Q2 trajectory required for PBREL pre-layout; extracted overshoot and dynamic SOA remain later gates
LOGIC_BUCK | Factory | LM5164QDDATQ1 | JLC C1850350 pre-order rechecked 2026-07-20 with stock risk still open | Authorized distributor stock plus JLCPCB pre-order plus PCBWay assembly | LM5013-Q1 and TPS54360B-Q1 conditional alternates retained | Verify SO PowerPAD assembly and 100 V margin | N/A | Close sourcing and logic-power value review before schematic freeze
LOGIC_BUCK_INDUCTOR | Factory | Automotive shielded power inductor class | Value and sourcing recheck before lock | JLCPCB/PCBWay assembly plus inductor vendor catalog | AEC-Q200 shielded inductor alternates retained | Verify saturation current package and reel availability | N/A | Close ripple saturation and sourcing review before schematic freeze
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

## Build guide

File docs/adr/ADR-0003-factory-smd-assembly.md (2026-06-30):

# ADR-0003: Factory SMD assembly

## Status
Accepted

## Context
The builder has only a soldering iron and no working rework station. Fine-pitch MCU and small SMD assembly should not be manual.

## Decision
All fine-pitch and small SMD parts are intended for factory assembly by JLCPCB/PCBWay.

## Consequences
BOM must be production-friendly. Garage assembly is limited to connectors, fuses, enclosure, wiring.

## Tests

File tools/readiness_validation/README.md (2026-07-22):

# Readiness Consistency Validation

This package owns cross-document release-readiness consistency only. It does
not validate electrical topology, KiCad geometry, firmware, or manufacturing
rules already covered by the engineering validators.

Sources of truth:

- `docs/adr/ADR-0015-can1-physical-layer-board-ownership.md` for CAN1 ownership.
- `docs/adr/ADR-0020-platform-evt-development-and-reference-loads.md` for the
  unified EVT and production lifecycle.
- The PB-100, LB-100, and FB-100 board-release blocker registers for active
  blocker IDs and counts.
- The reviewed FX18 footprint and inventory checks in `validate_board_order.py`
  for physical land implementation.

`consistency.py` verifies that the two three-board readiness CSV files and
`docs/product/final-readiness.md` report the same active blockers. It also
validates the ADR-0020 `EVT-LAYOUT-AUTHORIZED` through `PRODUCTION-RELEASE`
transitions, ordered PBREL-006/PBREL-007 stage closure, and aggregate PB-100
authorization against the post-prototype gate. It also
rejects stale active-document claims about ADR-0015, CAN1 ownership, FX18 lands,
or the selected 80 V MOSFET baseline.

Run it directly with:

```sh
make validate-readiness-consistency
```

It is also part of `make check`.

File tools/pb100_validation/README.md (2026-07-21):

# PB-100 Validator Structure

`tools/validate_pb100.py` is the stable command-line entrypoint. The validation
implementation is grouped here by engineering responsibility so that a change
to one design area does not require editing a monolithic validator.

| Module | Ownership |
|---|---|
| `common.py` | Repository paths, CSV/schema contracts, shared parsing and failure helpers |
| `runner.py` | Ordered check registry and CLI orchestration |
| `kicad.py` | KiCad scaffold, ERC, exported netlist, layout-artifact boundary |
| `symbols.py` | Symbol, footprint, pin evidence, instance maps and capture readiness |
| `release.py` | Schematic-freeze, blocker-register and board-print state consistency |
| `q2_qualification.py` | Q2 vendor redirect, replacement audit, empirical coupon/test plan and pre-layout gate |
| `release_evidence.py` | Generated five-blocker SOA, transient, Q1, factory, selected-part and freshness invariants |
| `pin_contracts.py` | Controller, input-protection and logic-power pin contracts |
| `outputs.py` | Generic output classes, values, SOA/freeze and closeout traces |
| `input_power.py` | Input protection and reverse-MOSFET evidence |
| `logic_power.py` | Protected logic rails, regulator values and closeout evidence |
| `can.py` | CAN1 physical-disable, readback, DNP and capture contracts |
| `budget.py` | Board-current budget, shunt and high-current path evidence |
| `current_telemetry.py` | Total/per-output current telemetry contracts |
| `thermal_telemetry.py` | NTC, temperature scaling and thermal telemetry contracts |
| `factory.py` | Factory assembly, sourcing snapshots and critical-key ownership |
| `garage.py` | Garage-installed connectors, fuses, wire and tooling evidence |
| `protection.py` | TVS/load-dump source, margin, overshoot and closeout evidence |
| `interface.py` | FX18/JPB1, LB resource binding and validation traceability |
| `review.py` | Test points, faults, review manifest and capture/release packet |

## Adding a check

1. Put the check in the module that owns the engineering decision.
2. Reuse contracts and helpers from `common.py`; do not duplicate file paths or
   CSV schemas in a domain module.
3. Add the top-level check to `CHECKS` in `runner.py` at the dependency-correct
   location. Helper checks called by another registered check do not need a
   second registry entry.
4. Keep `python3 tools/validate_pb100.py` and `make check` passing.

The runner also registers every callable `validate_*` hook exposed by these
modules so `PB-100-review-release-manifest.csv` retains the same hook validation
semantics as the former single-file implementation.

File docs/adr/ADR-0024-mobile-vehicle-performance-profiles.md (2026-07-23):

# ADR-0024: Mobile vehicle performance profiles

Status: Accepted
Date: 2026-07-23

## Decision

SVC Mobile stores vehicle performance configuration under
`software/mobile/vehicle-profiles/`, independently from manufacturer branding.
Both phone clients consume the same versioned JSON index and profile schema.

The profile owns dashboard scale and reference values such as RPM zones, idle
band, fuel capacity, gearbox count, and ice-warning threshold. BrandPack owns
logos, copy, and startup presentation. Telemetry quality, BLE state, CAN
decoding, device safety, and channel roles belong to neither profile.

Unknown technical values are explicit nulls. The Generic Motorcycle fallback
contains no assumed red zone, engine limits, gearbox count, or fuel values. The
BMW R1200GS K25 2007 profile has no rev-limiter value, so the dashboard must not
draw a limiter or cut-off marker.

## Consequences

Dashboard behavior can vary by confirmed vehicle capability without coupling
performance limits to trademarks or duplicating constants in Swift and Kotlin.
Changing a visual theme cannot change safety or performance thresholds.

The profile does not confirm CAN availability. BMW CAN remains listen-only and
signals stay unavailable until separately verified from recorded data. No
hardware, firmware, wire protocol, or Power Board architecture changes result
from this decision.

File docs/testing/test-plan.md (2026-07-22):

# Test Plan

## Phase boundary

PB-100 bench tests that require an assembled board are EVT validation gates.
Per ADR-0020, all three boards may enter controlled layout at
`EVT-LAYOUT-AUTHORIZED`; completed routing then enters `EVT-FAB-REVIEW`.
Reviewed DRC, parity, electrothermal/clamp-loop extraction, DFM and safety
evidence permit a five-board package at `EVT-FAB-AUTHORIZED`. Build inspection permits
`BENCH-VALIDATION`; physical bench records then gate
`MOTORCYCLE-VALIDATION` and production remains closed until reviewed Rev.2.
This flow preserves the validation intent of
`docs/adr/ADR-0013-pb-100-prelayout-vs-postprototype-validation.md` and the
staged evidence model of
`docs/adr/ADR-0017-pb-100-staged-release-authorization.md`; ADR-0020 controls
which release boundary those gates block. PBREL-007 blocks only production.

## Bench test before motorcycle

Required equipment:

- Current-limited lab power supply.
- Electronic load or fused dummy-load bank.
- Clamp meter or calibrated shunt.
- Oscilloscope or logic analyzer.
- CAN analyzer/logger.
- Thermal camera or thermocouples.
- Fused high-current harness fixture.

Do not run first-power, short-circuit, inrush, thermal, or CAN safety tests on
the motorcycle.

Do not run motorcycle first-power, field use, or production release before the
post-prototype validation gate in
`hardware/power-board/PB-100/PB-100-post-prototype-validation-gate.csv` is
complete.

PBREL-006/PBREL-007 EVT transition sequencing is tracked in
`hardware/power-board/PB-100/PB-100-staged-release-readiness.csv`.

Unit roles are fixed by
`hardware/power-board/PB-100/PB-100-evt-unit-allocation.csv`. `EVT-03` receives
fault/surge testing and must never be installed on the motorcycle. `EVT-04` is
reserved for motorcycle validation after its nondestructive bench pass.

### Ordered EVT bench sequence

1. Inspect DNP populations, polarity, isolation links and shorts.
2. Current-limited bring-up with all outputs disabled.
3. Verify each output and calibrate `OUT1_IMON` through `OUT10_IMON`.
4. Measure the four real auxiliary lamps and verify open-load, overload and
   short-circuit diagnosis with logged trip reasons.
5. Controlled 10 A, 20 A, 30 A and 40 A total-current load steps.
6. Calibrate INA228 and compare summed channel current with `IIN_SENSE`.
7. Verify `FOG_A_SW_IN` and `FOG_B_SW_IN` independently in both configurable
   behaviors: boot/reset-off, simultaneous requests, contact bounce, isolated
   stuck-input diagnosis, immediate pair-off and delayed channel start inside
   OUT3/OUT4 and OUT6/OUT7.
8. Verify OUT1 socket/compressor safeguards and both external C36 current
   directions; C36 uses an external clamp or shunt and remains unmanaged.
9. Verify mode masks, undervoltage response and shedding order: second fog pair,
   first fog pair, remaining managed outputs, then all outputs.
10. Record MOSFET, copper, via, shunt, connector and enclosure temperatures.
11. Run controlled overvoltage/load disconnect while recording synchronized
   `VBAT_RAW`, protected output, Q1/Q2 `VDS`, Q1/Q2 `VGS`, current and
   temperature.
12. Repeat inspection and parametric checks after abnormal-stress testing.

## PB-100 bench validation matrix

| ID | Area | Test | Pass condition |
|---|---|---|---|
| PB-BENCH-001 | Bring-up | Power PB-100 from current-limited supply at 6 V, 12 V, and 18 V with outputs disabled | No abnormal current draw; logic rail and `PB_PWR_GOOD` behave as expected |
| PB-BENCH-002 | Safe default | Hold LB-100 reset or disconnected and check `OUT1` through `OUT10` | All outputs remain off |
| PB-BENCH-003 | Reverse protection | Apply reverse polarity only through a current-limited fixture | No downstream rail energizes and no damage occurs |
| PB-BENCH-004 | Active cutoff/load dump | Apply the ADR-0016 surge envelope to the assembled engineering prototype while recording VBAT_RAW, VBAT_PROT, DGATE, HGATE, current, and Q2 temperature | LM74930-Q1 disconnects the load, VBAT_PROT peak stays below 60 V, Q2 remains inside extracted dynamic SOA, and repeated-pulse recovery has documented margin |
| PB-BENCH-005 | Per-output current telemetry | Measure each output at 0%, 25%, 50%, and 100% of configured current limit | Telemetry error is inside the schematic-defined calibration target |
| PB-BENCH-006 | Total input current telemetry | Load multiple outputs up to the 40 A board-budget target | Input current telemetry follows independent measurement inside calibration target |
| PB-BENCH-007 | OUT2 inrush envelope | Exercise the `PB-100-out2-soa-envelope.csv` pulse cases on a fused bench fixture | Controller does not exceed validated MOSFET SOA or fault timing |
| PB-BENCH-008 | Overcurrent and short fault | Apply controlled overcurrent and short-circuit tests per output class | Output faults and latches off inside the selected controller/FET SOA |
| PB-BENCH-009 | Thermal derating | Run representative high, medium, and low-current load combinations in enclosure conditions | Firmware sees PCB and power-zone temperature and derates before unsafe temperature |
| PB-BENCH-010 | Board current budget and passive Q1 cooling | Run the 40 A path at the qualified ambient while recording Q1 junction estimate, case, PCB copper, thermal pad, metal enclosure, and ambient temperatures | Firmware enforces the 40 A budget, Q1 stays at or below 150 °C, and the measured full passive path agrees with the extracted limit of 6.20 °C/W or better |
| PB-BENCH-011 | Fuse behavior | Open and overload fused outputs under controlled load | Fault state is visible and output is isolated by fuse behavior |
| PB-BENCH-012 | CAN1 listen-only | Connect CAN analyzer and attempt any Rev.1 CAN1 TX path with TX disable defaulted | No vehicle-CAN transmit frame is observed; disabled status is visible |
| PB-BENCH-013 | CAN2 expansion | Exercise CAN2 on bench only | CAN2 can transmit without affecting CAN1 listen-only policy |
| PB-BENCH-014 | B2B interface | Check `JPB1` control, fault, telemetry, ID, and reserve pins against the pin map | Pin behavior matches `PB-100-b2b-pin-map.csv` |
| PB-BENCH-015 | Vibration inspection | Inspect fuses, connectors, and harness strain relief after vibration exposure | No intermittent power, signal, or connector fault is observed |
| PB-BENCH-016 | Dual manual FOG requests | Exercise A-only, B-only, both inputs, simultaneous press, short/repeat press, maintained position, contact bounce, boot/reset, one stuck input, invalid configuration, undervoltage, overcurrent and thermal fault | Requests boot off; A controls only OUT3/OUT4; B controls only OUT6/OUT7; each pair sequences its two channels independently; pair-off is immediate; one stuck input does not block the other; safety denial clears both requests and no safety gate is bypassed |
| PB-BENCH-017 | Reference lamp currents | Measure each nominal 80 W and 70 W auxiliary lamp on its configured output | Actual steady and inrush current are stored and remain inside channel/fuse/SOA limits |
| PB-BENCH-018 | C36 bidirectional branch | Measure accessory-source and battery-charge directions with PB/LB both on and off using external current measurement | Both vendor-defined directions work through the separately fused branch; no current is attributed to `IIN_SENSE`; C36 is not used for starter current |
| PB-BENCH-019 | Operating modes and shedding | Exercise DAY NIGHT SERVICE_COMPRESSOR C36_RESCUE_CHARGE ENGINE_OFF and increasing generator deficit | Mutually exclusive loads are never admitted together; second fog pair sheds first, then first pair, then other managed outputs, and critical undervoltage disables OUT1 through OUT10 |

### Three-wire button identification

Perform this check with the switch disconnected from the motorcycle and from
PB-100/LB-100. Do not finalize the external harness until the record is complete.

1. Find the common conductor by continuity testing.
2. Verify common-to-each-remaining-conductor closure separately.
3. Record resistance in every pressed and released state.
4. Use diode mode to identify LEDs or other internal electronics.
5. Record wire colours, the complete state table and all measurements without
   assigning colour-based pin names beforehand.
6. Select exactly one assembly variant per input: active-low dry contact or the
   protected 12 V DNP option. Never populate incompatible variants together.

## Repository validation

Run the PB-100 artifact validator before committing schematic-planning or KiCad
scaffold changes:

```bash
python3 tools/validate_pb100.py
```

The validator checks CSV structure, KiCad scaffold syntax, the no-PCB-layout
boundary, preliminary symbol-library status, output instance coverage, and PB-100
net-naming safety rules.

Run firmware host tests after changing configuration, hardware-capability, or
safety-service contracts:

```bash
make -C firmware test
```

The hardware-capability tests verify that PB-100 generic output limits,
safe-default behavior, board current budget, and CAN1 read-only defaults are
accepted without binding accessory roles to physical outputs.
Repository validation also compares the compiled PB-100 capability constant with
the JSON hardware capability manifest.
Configuration acceptance tests verify startup rejects invalid configuration,
invalid hardware capability data, and configurations exceeding PB-100 limits.
Runtime boot tests verify rejected configuration leaves outputs off and runtime
services uninitialized. Store-backed runtime boot tests verify persisted records
are loaded before hardware capability acceptance.
Configuration store tests verify persisted user configuration is selected ahead
of firmware defaults after an update, including reserved-field rejection and
wrap-aware two-slot sequence selection.
Configuration update tests verify unsafe or hardware-incompatible configurations
are not prepared for persistence.
CAN RX log tests verify CAN1/CAN2 receive-only frame capture, invalid-frame
rejection, ring-buffer overwrite accounting, and saturating diagnostic counters.
They also verify that the CAN1 ISR feeds a separate always-lock-free SPSC
queue, that saturation drops only the new persistence copy, and that frames
arriving during a slow append/sync cannot replace or reorder the logger task's
pending batch. FatFs-adapter tests cover the identity-bearing 128-byte v2
session header and 44-byte/64-bit-microsecond records, preallocation,
size-based rotation, independent close attempts after sync failure, explicit
card restart/reopen, reopening the latest rotated session, format rollover
without overwriting v1 data, and truncation of torn or corrupt tails. The
target STM32 SDMMC/SPI `diskio` binding remains a hardware-integration test
gate.
CAN decode tests verify received frames publish internal state-change events
through the Event Bus without repeating unchanged states, and retry dropped edges
when the Event Bus is full.
Rule Event Bridge tests verify condition events drain into rule state, CAN-derived
events can reach rule evaluation, and non-rule events remain available for safety
dispatch.
Manual FOG control tests verify boot-off, debounce, stuck-input safe-off,
toggle behavior, safety denial and delayed second-pair requests. Rule condition
and rule text tests continue to verify the generic configuration grammar.
Rule Engine rule-set tests verify ordered multi-rule execution, skipped-rule
accounting, stop-on-first-failure behavior, and stale-telemetry denial through
the Output Manager budget path.
Rule Text tests verify multi-action `then[]` compilation into ordered
`svc_rule_t` arrays using caller-owned storage, canonical PWM action grammar,
and side-effect-free rejection before caller-owned buffers are modified.
Event Log tests verify fixed-size overwrite behavior and saturating dropped-entry
accounting.
System Safety tests verify battery cutoff, thermal cutoff, runtime current-budget
shedding, stale/invalid telemetry safe-off behavior, overflow-safe battery
elapsed-time conversion, and retry of dropped power-budget shed events.
Repository config validation checks schema rule string patterns, rule grammar,
non-empty `then[]`, mapped rule-action roles, and partial-PWM compatibility
against the configured outputs.
Rule Runtime tests verify CAN-derived condition events, retained fault dispatch,
ordered rule execution, and stale-telemetry denial in one processing step.

## PB-100 schematic-review traceability

- Bring-up and logic-rail tests trace to
  `hardware/power-board/PB-100/PB-100-logic-power-rail-trace.csv` and
  `hardware/power-board/PB-100/PB-100-logic-power-freeze-review.csv`, and
  `hardware/power-board/PB-100/PB-100-logic-power-value-freeze-checklist.csv`
  plus
  `hardware/power-board/PB-100/PB-100-logic-power-value-derivation-precheck.csv`
  and `hardware/power-board/PB-100/PB-100-logic-power-closeout-precheck.csv`.
- OUT2 pulse tests trace to
  `hardware/power-board/PB-100/PB-100-high-medium-output-baseline-trace.csv`
  `hardware/power-board/PB-100/PB-100-high-medium-output-freeze-review.csv`
  `hardware/power-board/PB-100/PB-100-output-stage-value-freeze-checklist.csv`
  `hardware/power-board/PB-100/PB-100-output-stage-value-derivation-precheck.csv`
  `hardware/power-board/PB-100/PB-100-output-stage-closeout-precheck.csv`
  and `hardware/power-board/PB-100/PB-100-out2-soa.md`.
- Output overcurrent, fuse, and class-limit tests trace to
  `hardware/power-board/PB-100/PB-100-high-medium-output-baseline-trace.csv`
  `hardware/power-board/PB-100/PB-100-high-medium-output-freeze-review.csv`
  and
  `hardware/power-board/PB-100/PB-100-low-current-output-baseline-trace.csv`
  plus `hardware/power-board/PB-100/PB-100-low-current-output-freeze-review.csv`
  plus `hardware/power-board/PB-100/PB-100-output-stage-value-freeze-checklist.csv`
  `hardware/power-board/PB-100/PB-100-output-stage-value-derivation-precheck.csv`
  and `hardware/power-board/PB-100/PB-100-output-stage-closeout-precheck.csv`.
- CAN1 listen-only tests trace to
  `hardware/power-board/PB-100/PB-100-can1-tx-disable-trace.csv`,
  `hardware/power-board/PB-100/PB-100-can1-tx-disable.md`, and
  `hardware/power-board/PB-100/PB-100-can1-safety-verification.csv`, plus
  `hardware/power-board/PB-100/PB-100-can1-production-dnp-review.csv` and
  `hardware/power-board/PB-100/PB-100-can1-reset-bench-checklist.csv`, and
  `hardware/power-board/PB-100/PB-100-can1-default-disable-freeze-checklist.csv`
  plus
  `hardware/power-board/PB-100/PB-100-can1-default-disable-derivation-precheck.csv`,
  and `hardware/power-board/PB-100/PB-100-can1-default-disable-closeout-precheck.csv`.
- Input reverse-protection tests trace to
  `hardware/power-board/PB-100/PB-100-input-reverse-package-trace.csv`,
  `hardware/power-board/PB-100/PB-100-input-reverse-freeze-review.csv`,
  `hardware/power-board/PB-100/PB-100-input-reverse-q1-freeze-checklist.csv`,
  `hardware/power-board/PB-100/PB-100-input-reverse-q1-derivation-precheck.csv`,
  `hardware/power-board/PB-100/PB-100-input-reverse-q1-closeout-precheck.csv`, and
  `hardware/power-board/PB-100/PB-100-input-reverse-protection.md`.
- TVS/load-dump tests trace to
  `hardware/power-board/PB-100/PB-100-tvs-load-dump-margin-trace.csv` and
  `hardware/power-board/PB-100/PB-100-tvs-load-dump-freeze-review.csv`, and
  `hardware/power-board/PB-100/PB-100-tvs-overshoot-escape-checklist.csv` plus
  `hardware/power-board/PB-100/PB-100-tvs-overshoot-validation-precheck.csv`
  and `hardware/power-board/PB-100/PB-100-tvs-overshoot-closeout-precheck.csv`.
- Current telemetry and current-budget tests trace to
  `hardware/power-board/PB-100/PB-100-current-telemetry-trace.csv`,
  `hardware/power-board/PB-100/PB-100-current-telemetry-freeze-review.csv`,
  `hardware/power-board/PB-100/PB-100-current-telemetry-value-freeze-checklist.csv`,
  `hardware/power-board/PB-100/PB-100-current-telemetry-value-derivation-precheck.csv`,
  `hardware/power-board/PB-100/PB-100-current-telemetry-closeout-precheck.csv`,
  `hardware/power-board/PB-100/PB-100-board-current-budget-trace.csv`,
  `hardware/power-board/PB-100/PB-100-board-current-budget-freeze-review.csv`,
  `hardware/power-board/PB-100/PB-100-board-current-budget-design-calculation.md`,
  `hardware/power-board/PB-100/PB-100-board-current-budget-value-freeze-checklist.csv`,
  `hardware/power-board/PB-100/PB-100-board-current-budget-value-derivation-precheck.csv`,
  `hardware/power-board/PB-100/PB-100-board-current-budget-closeout-precheck.csv`,
  and
  `docs/adr/ADR-0008-pb-100-current-budget.md`.
- Thermal derating tests trace to
  `hardware/power-board/PB-100/PB-100-thermal-telemetry-trace.csv` and
  `hardware/power-board/PB-100/PB-100-thermal-telemetry-freeze-review.csv`, and
  `hardware/power-board/PB-100/PB-100-thermal-telemetry-value-freeze-checklist.csv`
  plus
  `hardware/power-board/PB-100/PB-100-thermal-telemetry-value-derivation-precheck.csv`,
  and `hardware/power-board/PB-100/PB-100-thermal-telemetry-closeout-precheck.csv`.
- B2B interface tests trace to
  `hardware/power-board/PB-100/PB-100-b2b-interface-trace.csv`,
  `hardware/power-board/PB-100/PB-100-b2b-lb100-resource-binding.csv`,
  `hardware/power-board/PB-100/PB-100-b2b-lb100-pin-audit-checklist.csv`,
  `hardware/power-board/PB-100/PB-100-b2b-interface-freeze-checklist.csv`,
  `hardware/power-board/PB-100/PB-100-b2b-interface-closeout-precheck.csv`, and
  `hardware/power-board/PB-100/PB-100-b2b-pin-map.csv`.
- Vibration, connector, fuse, and harness ownership tests trace to
  `hardware/power-board/PB-100/PB-100-assembly-readiness-trace.csv` and
  `hardware/power-board/PB-100/PB-100-factory-assembly-freeze-checklist.csv`,
  `hardware/power-board/PB-100/PB-100-factory-assembly-sourcing-precheck.csv`,
  `hardware/power-board/PB-100/PB-100-factory-assembly-closeout-precheck.csv`,
  plus
  `hardware/power-board/PB-100/PB-100-garage-install-freeze-checklist.csv` and
  `hardware/power-board/PB-100/PB-100-garage-install-sourcing-precheck.csv` and
  `hardware/power-board/PB-100/PB-100-garage-install-closeout-precheck.csv`.

## Motorcycle test

Do not intentionally generate load dump, short circuit, overcurrent or another
destructive corner on the motorcycle. Use only an undamaged board that has
passed the required bench evidence.

1. Record battery voltage without additional loads, then install undamaged
   bench-passed `EVT-04`.
2. Verify DAY with auxiliary lamps off and no CAN errors.
3. Verify manual FOG toggle, NIGHT and each lamp pair separately.
4. Verify C36 powering an accessory and charging the battery from the approved
   power bank according to the C36 manufacturer procedure.
5. Verify cranking, idle and manual-defined control RPM while recording battery
   voltage and generator load.
6. Add only mode-permitted real loads in reviewed steps; test the compressor
   only after its purchase and current/fuse review.
7. Record board, wire and connector temperatures, vibration and fault logs.
8. Log CAN without transmitting and confirm the physical CAN1 TX-disabled
   status.
9. Disposition every Rev.1 finding into the Rev.2 review package.

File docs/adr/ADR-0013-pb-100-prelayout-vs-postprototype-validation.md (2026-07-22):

# ADR-0013: Split PB-100 pre-layout closure from post-prototype validation

## Status
Accepted — PB-100 release authorization superseded in part by ADR-0019

ADR-0019 permits controlled PB-100 Rev.1 EVT layout before every production
qualification item closes and requires the routed-board pre-fab review before
the five-board EVT order. The evidence-class split in this ADR remains active.

## Context
Some PB-100 checks need an assembled board or board stack. Examples include
current-telemetry calibration, thermal calibration, CAN1 no-transmit observation
with physical reset/unpowered states, output fault timing, fuse behavior, and
vibration inspection.

The board-print readiness artifacts previously mixed two different evidence
classes:

- Pre-layout evidence: schematic values, calculations, simulations, source
  evidence, assembly-process review, package/footprint review, test-point hooks,
  and bench procedures.
- Post-prototype evidence: measurements that require fabricated PB-100 hardware
  or the PB-100/LB-100 stack.

Requiring physical bench execution before the first PCB fabrication package is a
process deadlock.

## Decision
PB-100 schematic freeze requires only pre-layout evidence. First engineering-
prototype board-print authorization additionally requires the post-layout
verification defined by ADR-0017. Bench tests that need physical PB-100
hardware are deferred to a post-prototype validation gate.

Pre-layout closure may use:

- Datasheet calculations and design-value review.
- SPICE/surge/thermal simulation where applicable.
- Manufacturer, distributor, JLCPCB, and PCBWay process/source evidence.
- Package drawings, footprint review inputs, pin-map audits, and assembly notes.
- Test-point hooks and bench procedures that make later measurements possible.

Post-prototype validation requires actual bench records for PB-BENCH-001 through
PB-BENCH-015 before first motorcycle power, field use, or production release.
Those records do not block generation of the first prototype PCB fabrication
package after schematic freeze.

CAN1 remains safety-critical: ADR-0002 still requires CAN1 TX to be physically
DNP/open by default, and any vehicle-CAN TX path still requires a future ADR plus
explicit hardware action. ADR-0013 only moves physical no-transmit measurement
execution to the post-prototype gate; it does not permit a populated TX path.

## Consequences
PBREL blocker wording must distinguish pre-layout evidence from post-prototype
bench execution. Board-print gates may require bench plans, test hooks, and
simulation evidence, but not measurements that require a board that does not yet
exist.

Post-prototype validation is tracked separately in
`hardware/power-board/PB-100/PB-100-post-prototype-validation-gate.csv`.

ADR-0017 supersedes the former two-state authorization wording with explicit
`BLOCKED`, `LAYOUT-ONLY`, `PROTO-ONLY`, and `PRODUCTION-READY` transitions. It
does not change which evidence belongs before layout or after prototype build.

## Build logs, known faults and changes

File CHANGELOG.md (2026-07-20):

# Changelog

## Unreleased

- Initial SVC platform architecture.
- Added project constitution.
- Added Architecture Review draft.
- Added ADRs.
- Added Factory/Garage BOM drafts.
- Added firmware safety enforcement for delayed battery cutoff, runtime
  load-shedding, thermal derate, and PWM increase revalidation.
- Added system sleep/wake and parking-current ADR plus requirements.
- Hardened PB-100 KiCad validation to require fixed KiCad CLI, reject
  placeholder sheets, and enforce ERC/netlist/component/net gates.
- Added preliminary PB-100 KiCad child-sheet capture content that passes ERC and
  netlist export while keeping PCB layout blocked until schematic freeze.
- Added a PB-100 board-release blocker register so every conditional schematic
  freeze gate explicitly blocks PCB layout until its close evidence is complete.
- Added candidate LM5164-Q1 logic-power values for schematic review while
  keeping them not final before freeze.
- Added candidate PB-100 NTC divider values for schematic review while keeping
  thermal placement and calibration open.
- Added candidate PB-100 total-current telemetry values for schematic review
  while keeping shunt copper, bus ownership, and calibration open.
- Added candidate PB-100 CAN1 TX-disable hardware values while keeping vehicle
  CAN TX DNP/open and future-ADR gated.
- Added a PB-100/LB-100 B2B resource precheck for STM32H563 pin-binding review
  without freezing exact MCU pins.
- Aligned firmware rule action grammar across the JSON Schema, repository
  validator, and host-tested parser for supported roles and canonical 0..100
  PWM values.
- Hardened multi-action rule-set compilation so invalid action text is rejected
  before compiled rule entries are written.
- Hardened System Safety runtime current-budget enforcement so stale or invalid
  total-current telemetry disables active outputs.
- Hardened Runtime Boot store-loading invalid-argument handling so missing
  loaded-configuration storage leaves runtime safe/off.
- Hardened Configuration Store record validation to reject nonzero reserved
  fields before checksum/config acceptance.
- Fixed CAN Event Decode so dropped state-change events do not advance rule
  state and can be retried on the next matching frame.
- Hardened projected-current calculations to saturate on unsigned overflow and
  deny output starts or PWM increases.

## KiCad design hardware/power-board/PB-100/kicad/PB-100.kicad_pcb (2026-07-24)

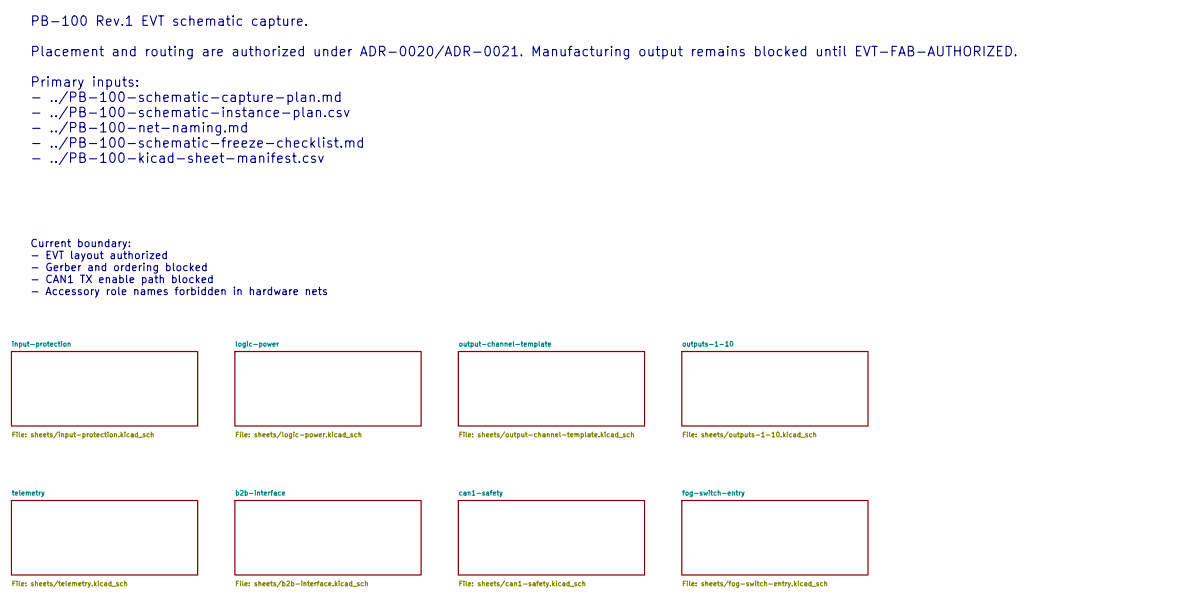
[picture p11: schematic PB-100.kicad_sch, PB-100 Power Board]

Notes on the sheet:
PB-100 Rev.1 EVT schematic capture. Placement and routing are authorized under ADR-0020/ADR-0021. Manufacturing output remains blocked until EVT-FAB-AUTHORIZED. Primary inputs: - ../PB-100-schematic-capture-plan.md - ../PB-100-schematic-instance-plan.csv - ../PB-100-net-naming.md - ../PB-100-schema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
Current boundary: - EVT layout authorized - Gerber and ordering blocked - CAN1 TX enable path blocked - Accessory role names forbidden in hardware nets

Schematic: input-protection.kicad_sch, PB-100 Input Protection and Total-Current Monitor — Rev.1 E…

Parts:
C20: 100nF 50V X7R DIFF; C0603
C21: 1nF 100V C0G; C0603
C22: 100nF 16V X7R; C0603
C23: 1nF PB I2C INT FILTER DNP; C0603; not fitted
C24: 10nF 50V X7R; C0603
CCAP1: 100nF 25V X7R; C0603
CSN1: 1nF 100V C0G DNP; C0603; not fitted
CSN2: 1nF 200V C0G DNP; C0603; not fitted
CVS1: CGA6N3X7R2A225M230AE 2.2uF 100V X7R; Ceff>=1uF@56V; C1210
D1: SM8S33AHM3/I; DO-218AC_Vishay_SM8S; not fitted
DZVS1: 56V AUTOMOTIVE ZENER; SOD-123F
J1: INPUT_CONNECTOR_CLASS_PRELIM (OFF-BOARD)
JIN1: 40A PCB PIGTAIL TO NEAR-BATTERY 50A FUSE; POWER_PIGTAIL_2xTH_40A
JISO1: EVT INPUT-STAGE ISOLATION LINK — FITTED FOR NORMA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; EVT_INPUT_ISOLATION_LINK_M4
Q1: IAUT300N08S5N012ATMA2; PG-HSOF-8-1_TOLL_Infineon
Q2: IAUTN15S6N025ATMA1; PG-HSOF-8-1_TOLL_Infineon
R3, R4: 42.2k 1%; R0603
R5: 1.00k 1%; R0603
R6: 10k 1%; R0603
R7: 0R REPLACEABLE Q1 GATE; R0603
R8: 0R REPLACEABLE Q2 GATE; R0603
R20, R21: 10R 0.1% SHUNT FILTER; R0603
R22: 1k 1% VBUS FILTER; R0603
R23: 10k PB I2C SDA PULL DNP; R0603; not fitted
R24: 10k PB I2C SCL PULL DNP; R0603; not fitted
R25: 47k PB I2C INT PULL DNP; R0603; not fitted
R26: 0R INPUT FAULT AGGREGATE; R0603
R27: 200k 0.1% 100V; R0603
R28: 10k 0.1%; R0603
R29: 1k 0.1%; R0603
RSH1: CSS4J-4026R-L500F 0.5mR 5W FOUR-TERMINAL; CSS4J-4026_Bourns
RSN1: 100R DNP Q1 DAMPING; R0603; not fitted
RSN2: 100R DNP Q2 DAMPING; R0603; not fitted
TP001: TEST GND; TestPoint_SMD_1.5mm
TP003: TEST VBAT_RAW; TestPoint_SMD_1.5mm
TP004: TEST VBAT_REV_PROT; TestPoint_SMD_1.5mm
TP005: TEST VBAT_PROT; TestPoint_SMD_1.5mm
TP006: TEST IIN_SHUNT_HI; TestPoint_SMD_1.5mm
TP007: TEST IIN_SHUNT_LO; TestPoint_SMD_1.5mm
TP008: TEST VBAT_SENSE; TestPoint_SMD_1.5mm
TP009: TEST IIN_SENSE; TestPoint_SMD_1.5mm
TP062: TEST Q1_GATE; TestPoint_SMD_1.5mm
TP063: TEST Q2_GATE; TestPoint_SMD_1.5mm
TP064: TEST INPUT_COMMON_SOURCE; TestPoint_SMD_1.5mm
TP065: TEST VBAT_PROT_PRELINK; TestPoint_SMD_1.5mm
U1: LM74930QRGERQ1; VQFN-24_RGE_4x4mm_P0.5mm_EP2.4mm
U2: INA228AQDGSRQ1 TOTAL CURRENT MONITOR; VSSOP-10_L3.0-W3.0-P0.50-LS4.9-BL

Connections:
IIN_MON_N: C20.2, R21.2, U2.9 (IN-)
IIN_MON_P: C20.1, R20.2, U2.10 (IN+)
IIN_SHUNT_HI: R20.1, RSH1.3 (SNS_IN), TP006.1 (IIN_SHUNT_HI)
IIN_SHUNT_LO: R21.1, RSH1.4 (SNS_OUT), TP007.1 (IIN_SHUNT_LO)
IIN_VBUS_FILTERED: C21.1, R22.2, U2.8 (VBUS)
INPUT_COMMON_SOURCE: CSN1.2, CSN2.2, Q1.2 (S), Q1.3 (S), Q1.4 (S), Q1.5 (S), Q1.6 (S), Q1.7 (S), Q1.8 (S), Q2.2 (S), Q2.3 (S), Q2.4 (S), Q2.5 (S), Q2.6 (S), Q2.7 (S), Q2.8 (S), TP064.1 (INPUT_COMMON_SOURCE), U1.2 (A), U1.15 (OUT)
INPUT_PROT_FAULT_N: R26.1, U1.12 (FLT)
LB_3V3_IO: R23.1, R24.1, R25.1; also elsewhere on the board
LM74930_CAP: CCAP1.1, U1.23 (CAP)
LM74930_OV: R4.2, R5.1, U1.5 (OV)
LM74930_OV_TOP_MID: R3.2, R4.1
LM74930_VS: CCAP1.2, CVS1.1, DZVS1.1, R6.2, U1.4 (UVLO), U1.6 (EN), U1.7 (MODE), U1.22 (VS)
PB_5V_OUT: C22.1, U2.6 (VS); also elsewhere on the board
Q1_DGATE: R7.1, U1.1 (DGATE)
Q1_GATE: Q1.1 (G), R7.2, TP062.1 (Q1_GATE)
Q1_SNUB: CSN1.1, RSN1.2
Q2_GATE: Q2.1 (G), R8.2, TP063.1 (Q2_GATE)
Q2_HGATE: R8.1, U1.14 (HGATE)
Q2_SNUB: CSN2.1, RSN2.2
VBAT_PROT: JISO1.2 (BOARD_LOADS), R22.1, R27.1, TP005.1 (VBAT_PROT); also elsewhere on the board
VBAT_PROT_PRELINK: JISO1.1 (INPUT_STAGE), RSH1.2 (PWR_OUT), TP065.1 (VBAT_PROT_PRELINK)
VBAT_RAW: D1.1 (K), J1.1 (VBAT_RAW), JIN1.1 (VBAT_RAW), Q2.Tab (D), R3.1, R6.1, RSN2.1, TP003.1 (VBAT_RAW)
VBAT_REV_PROT: Q1.Tab (D), RSH1.1 (PWR_IN), RSN1.1, TP004.1 (VBAT_REV_PROT), U1.18 (ISCP), U1.19 (CS-), U1.20 (CS+), U1.24 (C)
VBAT_SENSE_RAW: R27.2, R28.1, R29.1

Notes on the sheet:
Work queue: CAP-INP. ADR-0018/0019/0020 implementation. The raw-side 150 V Q2 and protected-side 80 V Q1 retain the reviewed LM74930-Q1 common-source hard-cutoff topology. RSH1 is a 0.5 mOhm four-terminal shunt. JISO1 is the mandatory removable input-stage isolation link; opening it prevents VBAT_P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

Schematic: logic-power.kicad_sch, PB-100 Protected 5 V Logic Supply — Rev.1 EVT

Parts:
C30: 2.2uF 100V X7R; C1210
C31: 100nF 100V X7R; C0805
C32: 10uF 100V BULK CANDIDATE; C1210
C33: 2.2nF 50V X7R; C0603
C34, C35: 22uF 10V X7R; C1210
C36: 100nF 16V X7R; C0603
C37: 10nF PGOOD FILTER DNP; C0603; not fitted
C38: 3.3nF 100V C0G TYPE3 CA; C0603
C39: 180pF 50V C0G TYPE3 CB; C0603
C40: 1nF 100V C0G DNP; C0603; not fitted
L1: 47uH SHIELDED AEC-Q200; Isat>=2.2A Irms>=1.2A; Inductor_12x12mm
R30: 332k 1%; R0603
R31: 100k 1%; R0603
R32: 41.2k 1%; R0603
R33: 158k 0.1%; R0603
R34: 49.9k 0.1%; R0603
R35: 47k PGOOD PULL-UP; R0603
R36: 110k 1% TYPE3 RA; R0603
R37: 100R BUCK SNUBBER DNP; R0603; not fitted
TP010: TEST PB_5V_OUT; TestPoint_SMD_1.5mm
TP011: TEST PB_PWR_GOOD; TestPoint_SMD_1.5mm
U3: LM5164QDDATQ1 100V 1A BUCK; SOIC-8_L4.9-W3.9-P1.27-LS6.0-BL-EP2.9

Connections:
BUCK_BST: C33.1, U3.7 (BST)
BUCK_EN_UVLO: R30.2, R31.1, U3.3 (EN/UVLO)
BUCK_FB: C39.2, R33.2, R34.1, U3.5 (FB)
BUCK_RAMP: C38.2, C39.1, R36.1
BUCK_RON_SET: R32.1, U3.4 (RON)
BUCK_SNUB: C40.1, R37.2
BUCK_SW: C33.2, C38.1, L1.1, R37.1, U3.8 (SW)
LB_3V3_IO: R35.1; also elsewhere on the board
PB_5V_OUT: C34.1, C35.1, C36.1, L1.2, R33.1, R36.2, TP010.1 (PB_5V_OUT); also elsewhere on the board
VBAT_PROT: C30.1, C31.1, C32.1, R30.1, U3.2 (VIN); also elsewhere on the board

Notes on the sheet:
Work queue: CAP-LOGIC. LM5164-Q1 100 V synchronous buck, 5.0 V / 1 A planning limit. The 300 kHz candidate uses 41.2k RON, 47uH shielded inductor, and a type-3 ripple-injection network. Switch-node copper must remain compact; thermal vias under the exposed pad and routed EMI evidence are required a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

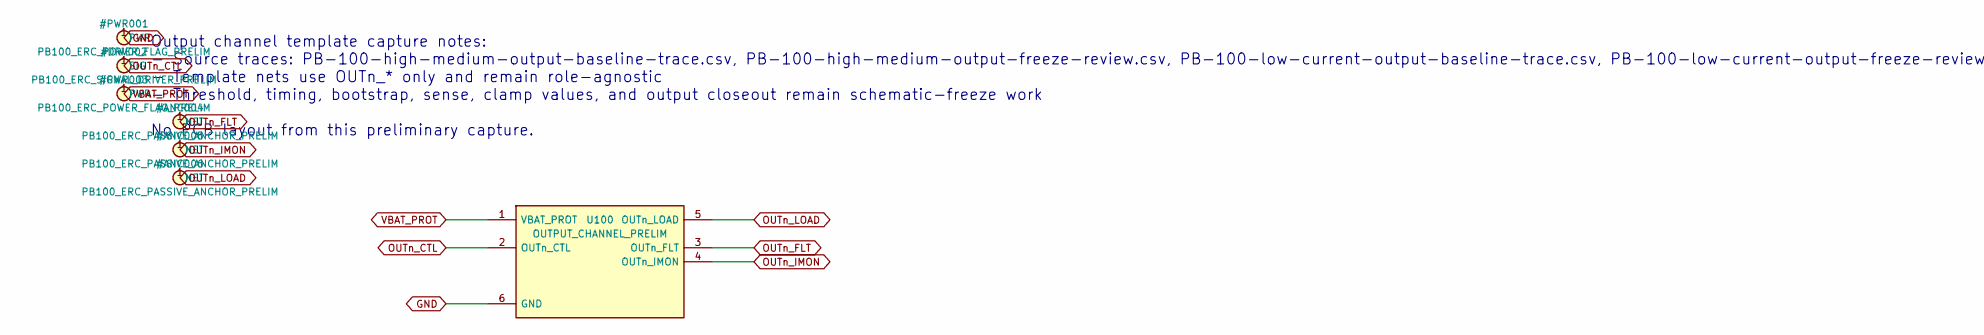
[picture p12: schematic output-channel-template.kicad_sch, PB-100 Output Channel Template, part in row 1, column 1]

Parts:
U100: OUTPUT_CHANNEL_PRELIM

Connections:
unnamed: U100.1 (VBAT_PROT), U100.6 (GND)
unnamed: U100.3 (OUTn_FLT), U100.4 (OUTn_IMON), U100.5 (OUTn_LOAD)

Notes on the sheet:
Output channel template capture notes: - Source traces: PB-100-high-medium-output-baseline-trace.csv, PB-100-high-medium-output-freeze-review.csv, PB-100-low-current-output-baseline-trace.csv, PB-100-low-current-output-freeze-review.csv, PB-100-output-stage-value-freeze-checklist.csv, PB-100-output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

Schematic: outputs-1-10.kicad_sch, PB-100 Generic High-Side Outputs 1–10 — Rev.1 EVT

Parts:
C1101, C1201, C1301, C1401, C1501, C1601, C1701, C1801, C1901, C2001: 680nF 16V X7R TMR; C0603
C1102, C1202, C1302, C1402, C1502, C1602, C1702, C1802, C1902, C2002: 470nF 25V X7R BST; C0603
C1103, C1203, C1303, C1403, C1503, C1603, C1703, C1803, C1903, C2003: 1nF 50V C0G ISCP; C0603
C1104, C1204, C1304, C1404, C1504, C1604, C1704, C1804, C1904, C2004: 100nF 100V X7R VS; C0805
C1105, C1205, C1305, C1405, C1505, C1605, C1705, C1805, C1905, C2005: 10nF 50V X7R IMON; C0603
C1106, C1206, C1306, C1406, C1506, C1606, C1706, C1806, C1906, C2006: 1nF 25V DNP GATE-SLEW; C0603; not fitted
C1107, C1207, C1307, C1407, C1507, C1607, C1707, C1807, C1907, C2007: 1nF 100V C0G DNP SNUBBER; C0603; not fitted
DCL101, DCL102, DCL103, DCL104, DCL105, DCL106, DCL107, DCL108, DCL109, DCL110: STPS40170CGY-TR 2x20A 170V COMMON-CATHODE; D2PAK_3_CommonCathode
F101, F102, F103, F104, F105, F106, F107, F108, F109, F110: OUTPUT_FUSE_CLASS_PRELIM (OFF-BOARD)
J101, J102, J103, J104, J105, J106, J107, J108, J109, J110: OUTPUT_CONNECTOR_CLASS_PRELIM (OFF-BOARD)
Q101, Q102, Q103, Q104, Q105, Q106, Q107, Q108, Q109, Q110: IAUT300N08S5N012ATMA2; PG-HSOF-8-1_TOLL_Infineon
QT101, QT102, QT103, QT104, QT105, QT106, QT107, QT108, QT109, QT110: MMBT3904-Q REMOTE TEMP DIODE; SOT-23-3_DBZ_TI
R1101, R1201, R1301, R1401, R1501, R1601, R1701, R1801, R1901, R2001: 470k 1%; R0603
R1102, R1202, R1302, R1402, R1502, R1602, R1702, R1802, R1902, R2002: 103k 1%; R0603
R1103, R1203, R1303, R1403, R1503, R1603, R1703, R1803, R1903, R2003: 12.4k 1%; R0603
R1104, R1204, R1304, R1404, R1504, R1604, R1704, R1804, R1904, R2004: 100R 1% RSET; R0603
R1105, R1305, R1405, R1505, R1605, R1705, R1805, R1905, R2005: 49.9k 1% RIWRN; R0603
R1106: 3.40k 1% RISCP; R0603
R1107, R1207, R1307, R1407, R1507, R1607, R1707, R1807, R1907, R2007: 12.1k 1% RIMON; R0603
R1108, R1208, R1308, R1408, R1508, R1608, R1708, R1808, R1908, R2008: 1k 1% IMON ADC SERIES; R0603
R1109, R1209, R1309, R1409, R1509, R1609, R1709, R1809, R1909, R2009: 100k CTL DEFAULT-OFF; R0603
R1110, R1210, R1310, R1410, R1510, R1610, R1710, R1810, R1910, R2010: 3.3R 1% REPLACEABLE PU; R0603
R1111, R1211, R1311, R1411, R1511, R1611, R1711, R1811, R1911, R2011: 0R REPLACEABLE PD; R0603
R1112, R1212, R1312, R1412, R1512, R1612, R1712, R1812, R1912, R2012: 10k FLT PULL-UP; R0603
R1113, R1213, R1313, R1413, R1513, R1613, R1713, R1813, R1913, R2013: 100R DNP DRAIN-SOURCE SNUBBER; R0603; not fitted
R1205: 67.3k 1% RIWRN; R0603
R1206: 2.61k 1% RISCP; R0603
R1306, R1406, R1606, R1706, R2006: 3.83k 1% RISCP; R0603
R1506, R1806, R1906: 3.74k 1% RISCP; R0603
RSH101: CSS4J-4026 1.0mR FOUR-TERMINAL; CSS4J-4026_Bourns
RSH102: CSS4J-4026 0.5mR FOUR-TERMINAL; CSS4J-4026_Bourns
RSH103, RSH104, RSH106, RSH107, RSH110: CSS4J-4026 1.5mR FOUR-TERMINAL; CSS4J-4026_Bourns
RSH105, RSH108, RSH109: CSS4J-4026 3.0mR FOUR-TERMINAL; CSS4J-4026_Bourns
TP022: TEST OUT1_CTL; TestPoint_SMD_1.5mm
TP023: TEST OUT1_FLT; TestPoint_SMD_1.5mm
TP024: TEST OUT1_IMON; TestPoint_SMD_1.5mm
TP025: TEST OUT1_SWITCHED; TestPoint_SMD_1.5mm
TP026: TEST OUT2_CTL; TestPoint_SMD_1.5mm
TP027: TEST OUT2_FLT; TestPoint_SMD_1.5mm
TP028: TEST OUT2_IMON; TestPoint_SMD_1.5mm
TP029: TEST OUT2_SWITCHED; TestPoint_SMD_1.5mm
TP030: TEST OUT3_CTL; TestPoint_SMD_1.5mm
TP031: TEST OUT3_FLT; TestPoint_SMD_1.5mm
TP032: TEST OUT3_IMON; TestPoint_SMD_1.5mm
TP033: TEST OUT3_SWITCHED; TestPoint_SMD_1.5mm
TP034: TEST OUT4_CTL; TestPoint_SMD_1.5mm
TP035: TEST OUT4_FLT; TestPoint_SMD_1.5mm
TP036: TEST OUT4_IMON; TestPoint_SMD_1.5mm
TP037: TEST OUT4_SWITCHED; TestPoint_SMD_1.5mm
TP038: TEST OUT5_CTL; TestPoint_SMD_1.5mm
TP039: TEST OUT5_FLT; TestPoint_SMD_1.5mm
TP040: TEST OUT5_IMON; TestPoint_SMD_1.5mm
TP041: TEST OUT5_SWITCHED; TestPoint_SMD_1.5mm
TP042: TEST OUT6_CTL; TestPoint_SMD_1.5mm
TP043: TEST OUT6_FLT; TestPoint_SMD_1.5mm
TP044: TEST OUT6_IMON; TestPoint_SMD_1.5mm
TP045: TEST OUT6_SWITCHED; TestPoint_SMD_1.5mm
TP046: TEST OUT7_CTL; TestPoint_SMD_1.5mm
TP047: TEST OUT7_FLT; TestPoint_SMD_1.5mm
TP048: TEST OUT7_IMON; TestPoint_SMD_1.5mm
TP049: TEST OUT7_SWITCHED; TestPoint_SMD_1.5mm
TP050: TEST OUT8_CTL; TestPoint_SMD_1.5mm
TP051: TEST OUT8_FLT; TestPoint_SMD_1.5mm
TP052: TEST OUT8_IMON; TestPoint_SMD_1.5mm
TP053: TEST OUT8_SWITCHED; TestPoint_SMD_1.5mm
TP054: TEST OUT9_CTL; TestPoint_SMD_1.5mm
TP055: TEST OUT9_FLT; TestPoint_SMD_1.5mm
TP056: TEST OUT9_IMON; TestPoint_SMD_1.5mm
TP057: TEST OUT9_SWITCHED; TestPoint_SMD_1.5mm
TP058: TEST OUT10_CTL; TestPoint_SMD_1.5mm
TP059: TEST OUT10_FLT; TestPoint_SMD_1.5mm
TP060: TEST OUT10_IMON; TestPoint_SMD_1.5mm
TP061: TEST OUT10_SWITCHED; TestPoint_SMD_1.5mm
U101, U102, U103, U104, U105, U106, U107, U108, U109, U110: TPS48110AQDGXRQ1; VSSOP-20_19P-L5.0-W3.0-P0.50-LS5.0-BL_PE16
W101: OUT1 PCB PIGTAIL TO OFF-BOARD FUSE/SEALED CONNECT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; POWER_PIGTAIL_2xTH_20A
W102: OUT2 PCB PIGTAIL TO OFF-BOARD FUSE/SEALED CONNECT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; POWER_PIGTAIL_2xTH_20A
W103: OUT3 PCB PIGTAIL TO OFF-BOARD FUSE/SEALED CONNECT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; POWER_PIGTAIL_2xTH_20A
W104: OUT4 PCB PIGTAIL TO OFF-BOARD FUSE/SEALED CONNECT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; POWER_PIGTAIL_2xTH_20A
W105: OUT5 PCB PIGTAIL TO OFF-BOARD FUSE/SEALED CONNECT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; POWER_PIGTAIL_2xTH_20A
W106: OUT6 PCB PIGTAIL TO OFF-BOARD FUSE/SEALED CONNECT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; POWER_PIGTAIL_2xTH_20A
W107: OUT7 PCB PIGTAIL TO OFF-BOARD FUSE/SEALED CONNECT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; POWER_PIGTAIL_2xTH_20A
W108: OUT8 PCB PIGTAIL TO OFF-BOARD FUSE/SEALED CONNECT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; POWER_PIGTAIL_2xTH_20A
W109: OUT9 PCB PIGTAIL TO OFF-BOARD FUSE/SEALED CONNECT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; POWER_PIGTAIL_2xTH_20A
W110: OUT10 PCB PIGTAIL TO OFF-BOARD FUSE/SEALED CONNEC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; POWER_PIGTAIL_2xTH_20A

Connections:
LB_3V3_IO: R1112.1, R1212.1, R1312.1, R1412.1, R1512.1, R1612.1, R1712.1, R1812.1, R1912.1, R2012.1; also elsewhere on the board
unnamed: F101.2 (OUT), J101.1 (POS)
unnamed: F102.2 (OUT), J102.1 (POS)
unnamed: F103.2 (OUT), J103.1 (POS)
unnamed: F104.2 (OUT), J104.1 (POS)
unnamed: F105.2 (OUT), J105.1 (POS)
unnamed: F106.2 (OUT), J106.1 (POS)
unnamed: F107.2 (OUT), J107.1 (POS)
unnamed: F108.2 (OUT), J108.1 (POS)
unnamed: F109.2 (OUT), J109.1 (POS)
unnamed: F110.2 (OUT), J110.1 (POS)
OUT1_BST: C1102.1, U101.12 (BST)
OUT1_CS_N: C1103.2, RSH101.4 (SNS_OUT), U101.17 (CS-)
OUT1_CS_P: R1104.2, U101.18 (CS+)
OUT1_CS_P_KELVIN: R1104.1, R1106.1, RSH101.3 (SNS_IN)
OUT1_DIODE: QT101.2 (B), QT101.3 (C), U101.10 (DIODE)
OUT1_EN_UVLO: R1102.2, R1103.1, U101.1 (EN/UVLO)
OUT1_FET_DRAIN: Q101.Tab (D), R1113.1, RSH101.2 (PWR_OUT)
OUT1_GATE: C1106.1, Q101.1 (G), R1110.2, R1111.2
OUT1_IMON_RAW: R1107.1, R1108.1, U101.7 (IMON)
OUT1_ISCP: C1103.1, R1106.2, U101.19 (ISCP)
OUT1_IWRN: R1105.1, U101.8 (IWRN)
OUT1_OV: R1101.2, R1102.1, U101.2 (OV)
OUT1_PD: R1111.1, U101.14 (PD)
OUT1_PU: R1110.1, U101.15 (PU)
OUT1_SNUB: C1107.1, R1113.2
OUT1_SWITCHED: C1102.2, C1106.2, C1107.2, DCL101.2 (K), F101.1 (IN), Q101.2 (S), Q101.3 (S), Q101.4 (S), Q101.5 (S), Q101.6 (S), Q101.7 (S), Q101.8 (S), TP025.1 (OUT1_SWITCHED), U101.13 (SRC), W101.1 (POS)
OUT1_TMR: C1101.1, U101.9 (TMR)
OUT2_BST: C1202.1, U102.12 (BST)
OUT2_CS_N: C1203.2, RSH102.4 (SNS_OUT), U102.17 (CS-)
OUT2_CS_P: R1204.2, U102.18 (CS+)
OUT2_CS_P_KELVIN: R1204.1, R1206.1, RSH102.3 (SNS_IN)
OUT2_DIODE: QT102.2 (B), QT102.3 (C), U102.10 (DIODE)
OUT2_EN_UVLO: R1202.2, R1203.1, U102.1 (EN/UVLO)
OUT2_FET_DRAIN: Q102.Tab (D), R1213.1, RSH102.2 (PWR_OUT)
OUT2_GATE: C1206.1, Q102.1 (G), R1210.2, R1211.2
OUT2_IMON_RAW: R1207.1, R1208.1, U102.7 (IMON)
OUT2_ISCP: C1203.1, R1206.2, U102.19 (ISCP)
OUT2_IWRN: R1205.1, U102.8 (IWRN)
OUT2_OV: R1201.2, R1202.1, U102.2 (OV)
OUT2_PD: R1211.1, U102.14 (PD)
OUT2_PU: R1210.1, U102.15 (PU)
OUT2_SNUB: C1207.1, R1213.2
OUT2_SWITCHED: C1202.2, C1206.2, C1207.2, DCL102.2 (K), F102.1 (IN), Q102.2 (S), Q102.3 (S), Q102.4 (S), Q102.5 (S), Q102.6 (S), Q102.7 (S), Q102.8 (S), TP029.1 (OUT2_SWITCHED), U102.13 (SRC), W102.1 (POS)
OUT2_TMR: C1201.1, U102.9 (TMR)
OUT3_BST: C1302.1, U103.12 (BST)
OUT3_CS_N: C1303.2, RSH103.4 (SNS_OUT), U103.17 (CS-)
OUT3_CS_P: R1304.2, U103.18 (CS+)
OUT3_CS_P_KELVIN: R1304.1, R1306.1, RSH103.3 (SNS_IN)
OUT3_DIODE: QT103.2 (B), QT103.3 (C), U103.10 (DIODE)
OUT3_EN_UVLO: R1302.2, R1303.1, U103.1 (EN/UVLO)
OUT3_FET_DRAIN: Q103.Tab (D), R1313.1, RSH103.2 (PWR_OUT)
OUT3_GATE: C1306.1, Q103.1 (G), R1310.2, R1311.2
OUT3_IMON_RAW: R1307.1, R1308.1, U103.7 (IMON)
OUT3_ISCP: C1303.1, R1306.2, U103.19 (ISCP)
OUT3_IWRN: R1305.1, U103.8 (IWRN)
OUT3_OV: R1301.2, R1302.1, U103.2 (OV)
OUT3_PD: R1311.1, U103.14 (PD)
OUT3_PU: R1310.1, U103.15 (PU)
OUT3_SNUB: C1307.1, R1313.2
OUT3_SWITCHED: C1302.2, C1306.2, C1307.2, DCL103.2 (K), F103.1 (IN), Q103.2 (S), Q103.3 (S), Q103.4 (S), Q103.5 (S), Q103.6 (S), Q103.7 (S), Q103.8 (S), TP033.1 (OUT3_SWITCHED), U103.13 (SRC), W103.1 (POS)
OUT3_TMR: C1301.1, U103.9 (TMR)
OUT4_BST: C1402.1, U104.12 (BST)
OUT4_CS_N: C1403.2, RSH104.4 (SNS_OUT), U104.17 (CS-)
OUT4_CS_P: R1404.2, U104.18 (CS+)
OUT4_CS_P_KELVIN: R1404.1, R1406.1, RSH104.3 (SNS_IN)
OUT4_DIODE: QT104.2 (B), QT104.3 (C), U104.10 (DIODE)
OUT4_EN_UVLO: R1402.2, R1403.1, U104.1 (EN/UVLO)
OUT4_FET_DRAIN: Q104.Tab (D), R1413.1, RSH104.2 (PWR_OUT)
OUT4_GATE: C1406.1, Q104.1 (G), R1410.2, R1411.2
OUT4_IMON_RAW: R1407.1, R1408.1, U104.7 (IMON)
OUT4_ISCP: C1403.1, R1406.2, U104.19 (ISCP)
OUT4_IWRN: R1405.1, U104.8 (IWRN)
OUT4_OV: R1401.2, R1402.1, U104.2 (OV)
OUT4_PD: R1411.1, U104.14 (PD)
OUT4_PU: R1410.1, U104.15 (PU)
OUT4_SNUB: C1407.1, R1413.2
OUT4_SWITCHED: C1402.2, C1406.2, C1407.2, DCL104.2 (K), F104.1 (IN), Q104.2 (S), Q104.3 (S), Q104.4 (S), Q104.5 (S), Q104.6 (S), Q104.7 (S), Q104.8 (S), TP037.1 (OUT4_SWITCHED), U104.13 (SRC), W104.1 (POS)
OUT4_TMR: C1401.1, U104.9 (TMR)
OUT5_BST: C1502.1, U105.12 (BST)
OUT5_CS_N: C1503.2, RSH105.4 (SNS_OUT), U105.17 (CS-)
OUT5_CS_P: R1504.2, U105.18 (CS+)
OUT5_CS_P_KELVIN: R1504.1, R1506.1, RSH105.3 (SNS_IN)
OUT5_DIODE: QT105.2 (B), QT105.3 (C), U105.10 (DIODE)
OUT5_EN_UVLO: R1502.2, R1503.1, U105.1 (EN/UVLO)
OUT5_FET_DRAIN: Q105.Tab (D), R1513.1, RSH105.2 (PWR_OUT)
OUT5_GATE: C1506.1, Q105.1 (G), R1510.2, R1511.2
OUT5_IMON_RAW: R1507.1, R1508.1, U105.7 (IMON)
OUT5_ISCP: C1503.1, R1506.2, U105.19 (ISCP)
OUT5_IWRN: R1505.1, U105.8 (IWRN)
OUT5_OV: R1501.2, R1502.1, U105.2 (OV)
OUT5_PD: R1511.1, U105.14 (PD)
OUT5_PU: R1510.1, U105.15 (PU)
OUT5_SNUB: C1507.1, R1513.2
OUT5_SWITCHED: C1502.2, C1506.2, C1507.2, DCL105.2 (K), F105.1 (IN), Q105.2 (S), Q105.3 (S), Q105.4 (S), Q105.5 (S), Q105.6 (S), Q105.7 (S), Q105.8 (S), TP041.1 (OUT5_SWITCHED), U105.13 (SRC), W105.1 (POS)
OUT5_TMR: C1501.1, U105.9 (TMR)
OUT6_BST: C1602.1, U106.12 (BST)
OUT6_CS_N: C1603.2, RSH106.4 (SNS_OUT), U106.17 (CS-)
OUT6_CS_P: R1604.2, U106.18 (CS+)
OUT6_CS_P_KELVIN: R1604.1, R1606.1, RSH106.3 (SNS_IN)
OUT6_DIODE: QT106.2 (B), QT106.3 (C), U106.10 (DIODE)
OUT6_EN_UVLO: R1602.2, R1603.1, U106.1 (EN/UVLO)
OUT6_FET_DRAIN: Q106.Tab (D), R1613.1, RSH106.2 (PWR_OUT)
OUT6_GATE: C1606.1, Q106.1 (G), R1610.2, R1611.2
OUT6_IMON_RAW: R1607.1, R1608.1, U106.7 (IMON)
OUT6_ISCP: C1603.1, R1606.2, U106.19 (ISCP)
OUT6_IWRN: R1605.1, U106.8 (IWRN)
OUT6_OV: R1601.2, R1602.1, U106.2 (OV)
OUT6_PD: R1611.1, U106.14 (PD)
OUT6_PU: R1610.1, U106.15 (PU)
OUT6_SNUB: C1607.1, R1613.2
OUT6_SWITCHED: C1602.2, C1606.2, C1607.2, DCL106.2 (K), F106.1 (IN), Q106.2 (S), Q106.3 (S), Q106.4 (S), Q106.5 (S), Q106.6 (S), Q106.7 (S), Q106.8 (S), TP045.1 (OUT6_SWITCHED), U106.13 (SRC), W106.1 (POS)
OUT6_TMR: C1601.1, U106.9 (TMR)
OUT7_BST: C1702.1, U107.12 (BST)
OUT7_CS_N: C1703.2, RSH107.4 (SNS_OUT), U107.17 (CS-)
OUT7_CS_P: R1704.2, U107.18 (CS+)
OUT7_CS_P_KELVIN: R1704.1, R1706.1, RSH107.3 (SNS_IN)
OUT7_DIODE: QT107.2 (B), QT107.3 (C), U107.10 (DIODE)
OUT7_EN_UVLO: R1702.2, R1703.1, U107.1 (EN/UVLO)
OUT7_FET_DRAIN: Q107.Tab (D), R1713.1, RSH107.2 (PWR_OUT)
OUT7_GATE: C1706.1, Q107.1 (G), R1710.2, R1711.2
OUT7_IMON_RAW: R1707.1, R1708.1, U107.7 (IMON)
OUT7_ISCP: C1703.1, R1706.2, U107.19 (ISCP)
OUT7_IWRN: R1705.1, U107.8 (IWRN)
OUT7_OV: R1701.2, R1702.1, U107.2 (OV)
OUT7_PD: R1711.1, U107.14 (PD)
OUT7_PU: R1710.1, U107.15 (PU)
OUT7_SNUB: C1707.1, R1713.2
OUT7_SWITCHED: C1702.2, C1706.2, C1707.2, DCL107.2 (K), F107.1 (IN), Q107.2 (S), Q107.3 (S), Q107.4 (S), Q107.5 (S), Q107.6 (S), Q107.7 (S), Q107.8 (S), TP049.1 (OUT7_SWITCHED), U107.13 (SRC), W107.1 (POS)
OUT7_TMR: C1701.1, U107.9 (TMR)
OUT8_BST: C1802.1, U108.12 (BST)
OUT8_CS_N: C1803.2, RSH108.4 (SNS_OUT), U108.17 (CS-)
OUT8_CS_P: R1804.2, U108.18 (CS+)
OUT8_CS_P_KELVIN: R1804.1, R1806.1, RSH108.3 (SNS_IN)
OUT8_DIODE: QT108.2 (B), QT108.3 (C), U108.10 (DIODE)
OUT8_EN_UVLO: R1802.2, R1803.1, U108.1 (EN/UVLO)
OUT8_FET_DRAIN: Q108.Tab (D), R1813.1, RSH108.2 (PWR_OUT)
OUT8_GATE: C1806.1, Q108.1 (G), R1810.2, R1811.2
OUT8_IMON_RAW: R1807.1, R1808.1, U108.7 (IMON)
OUT8_ISCP: C1803.1, R1806.2, U108.19 (ISCP)
OUT8_IWRN: R1805.1, U108.8 (IWRN)
OUT8_OV: R1801.2, R1802.1, U108.2 (OV)
OUT8_PD: R1811.1, U108.14 (PD)
OUT8_PU: R1810.1, U108.15 (PU)
OUT8_SNUB: C1807.1, R1813.2
OUT8_SWITCHED: C1802.2, C1806.2, C1807.2, DCL108.2 (K), F108.1 (IN), Q108.2 (S), Q108.3 (S), Q108.4 (S), Q108.5 (S), Q108.6 (S), Q108.7 (S), Q108.8 (S), TP053.1 (OUT8_SWITCHED), U108.13 (SRC), W108.1 (POS)
OUT8_TMR: C1801.1, U108.9 (TMR)
OUT9_BST: C1902.1, U109.12 (BST)
OUT9_CS_N: C1903.2, RSH109.4 (SNS_OUT), U109.17 (CS-)
OUT9_CS_P: R1904.2, U109.18 (CS+)
OUT9_CS_P_KELVIN: R1904.1, R1906.1, RSH109.3 (SNS_IN)
OUT9_DIODE: QT109.2 (B), QT109.3 (C), U109.10 (DIODE)
OUT9_EN_UVLO: R1902.2, R1903.1, U109.1 (EN/UVLO)
OUT9_FET_DRAIN: Q109.Tab (D), R1913.1, RSH109.2 (PWR_OUT)
OUT9_GATE: C1906.1, Q109.1 (G), R1910.2, R1911.2
OUT9_IMON_RAW: R1907.1, R1908.1, U109.7 (IMON)
OUT9_ISCP: C1903.1, R1906.2, U109.19 (ISCP)
OUT9_IWRN: R1905.1, U109.8 (IWRN)
OUT9_OV: R1901.2, R1902.1, U109.2 (OV)
OUT9_PD: R1911.1, U109.14 (PD)
OUT9_PU: R1910.1, U109.15 (PU)
OUT9_SNUB: C1907.1, R1913.2
OUT9_SWITCHED: C1902.2, C1906.2, C1907.2, DCL109.2 (K), F109.1 (IN), Q109.2 (S), Q109.3 (S), Q109.4 (S), Q109.5 (S), Q109.6 (S), Q109.7 (S), Q109.8 (S), TP057.1 (OUT9_SWITCHED), U109.13 (SRC), W109.1 (POS)
OUT9_TMR: C1901.1, U109.9 (TMR)
OUT10_BST: C2002.1, U110.12 (BST)
OUT10_CS_N: C2003.2, RSH110.4 (SNS_OUT), U110.17 (CS-)
OUT10_CS_P: R2004.2, U110.18 (CS+)
OUT10_CS_P_KELVIN: R2004.1, R2006.1, RSH110.3 (SNS_IN)
OUT10_DIODE: QT110.2 (B), QT110.3 (C), U110.10 (DIODE)
OUT10_EN_UVLO: R2002.2, R2003.1, U110.1 (EN/UVLO)
OUT10_FET_DRAIN: Q110.Tab (D), R2013.1, RSH110.2 (PWR_OUT)
OUT10_GATE: C2006.1, Q110.1 (G), R2010.2, R2011.2
OUT10_IMON_RAW: R2007.1, R2008.1, U110.7 (IMON)
OUT10_ISCP: C2003.1, R2006.2, U110.19 (ISCP)
OUT10_IWRN: R2005.1, U110.8 (IWRN)
OUT10_OV: R2001.2, R2002.1, U110.2 (OV)
OUT10_PD: R2011.1, U110.14 (PD)
OUT10_PU: R2010.1, U110.15 (PU)
OUT10_SNUB: C2007.1, R2013.2
OUT10_SWITCHED: C2002.2, C2006.2, C2007.2, DCL110.2 (K), F110.1 (IN), Q110.2 (S), Q110.3 (S), Q110.4 (S), Q110.5 (S), Q110.6 (S), Q110.7 (S), Q110.8 (S), TP061.1 (OUT10_SWITCHED), U110.13 (SRC), W110.1 (POS)
OUT10_TMR: C2001.1, U110.9 (TMR)
VBAT_PROT: C1104.1, C1204.1, C1304.1, C1404.1, C1504.1, C1604.1, C1704.1, C1804.1, C1904.1, C2004.1, R1101.1, R1201.1, R1301.1, R1401.1, R1501.1, R1601.1, R1701.1, R1801.1, R1901.1, R2001.1, RSH101.1 (PWR_IN), RSH102.1 (PWR_IN), RSH103.1 (PWR_IN), RSH104.1 (PWR_IN), RSH105.1 (PWR_IN), RSH106.1 (PWR_IN), RSH107.1 (PWR_IN), RSH108.1 (PWR_IN), RSH109.1 (PWR_IN), RSH110.1 (PWR_IN), U101.20 (VS), U102.20 (VS), U103.20 (VS), U104.20 (VS), U105.20 (VS), U106.20 (VS), U107.20 (VS), U108.20 (VS), U109.20 (VS), U110.20 (VS); also elsewhere on the board

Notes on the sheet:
Work queue: CAP-OUT-INST. Ten role-free TPS48110-Q1 channels implement the accepted 80 V TOLL architecture. Each channel includes a four-terminal shunt, 55.7 V/6.0 V OV/UVLO ladder, hardware current thresholds, timer, bootstrap, replaceable PU/PD resistors, DNP slew/snubber sites, independent remot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

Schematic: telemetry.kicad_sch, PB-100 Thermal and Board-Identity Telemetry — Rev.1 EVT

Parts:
C61, C64, C67: 10nF 50V X7R; C0603
R61, R64, R67: 4.7k 1% AEC-Q200; R0603
R62, R65, R68: 1k 1% ADC SERIES; R0603
RID1: PB REV1 ID: 10k/10k 0.1% DIVIDER; Board_ID_Divider_0603x2
RT1, RT2, RT3: NTCGS103JF103FT8 10k 1% B3435 AEC-Q200; R0402
TP002: TEST AGND; TestPoint_SMD_1.5mm
TP012: TEST LB_3V3_IO; TestPoint_SMD_1.5mm
TP013: TEST PB_I2C_SCL; TestPoint_SMD_1.5mm
TP014: TEST PB_I2C_SDA; TestPoint_SMD_1.5mm
TP015: TEST PB_I2C_INT; TestPoint_SMD_1.5mm
TP016: TEST TEMP_PCB; TestPoint_SMD_1.5mm
TP017: TEST TEMP_PWR_A; TestPoint_SMD_1.5mm
TP018: TEST TEMP_PWR_B; TestPoint_SMD_1.5mm
TP019: TEST CAN1_TX_DISABLE_CMD; TestPoint_SMD_1.5mm
TP020: TEST CAN1_TX_DISABLED_STATUS; TestPoint_SMD_1.5mm
TP021: TEST CAN1_RX_ROUTE; TestPoint_SMD_1.5mm

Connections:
LB_3V3_IO: R61.1, R64.1, R67.1, RID1.1 (LB_3V3_IO), TP012.1 (LB_3V3_IO); also elsewhere on the board
TEMP_PCB_RAW: R61.2, R62.1, RT1.1
TEMP_PWR_A_RAW: R64.2, R65.1, RT2.1
TEMP_PWR_B_RAW: R67.2, R68.1, RT3.1

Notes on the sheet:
Work queue: CAP-TEL. Three role-independent 10k AEC-Q200 NTC dividers use 4.7k pull-ups to LB_3V3_IO, 1k ADC isolation, and 10nF filters. Sensor placement targets board reference, input/OUT2 hot zone, and medium-output/buck zone. RID1 is a physical two-resistor board-ID divider. Calibration and thr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

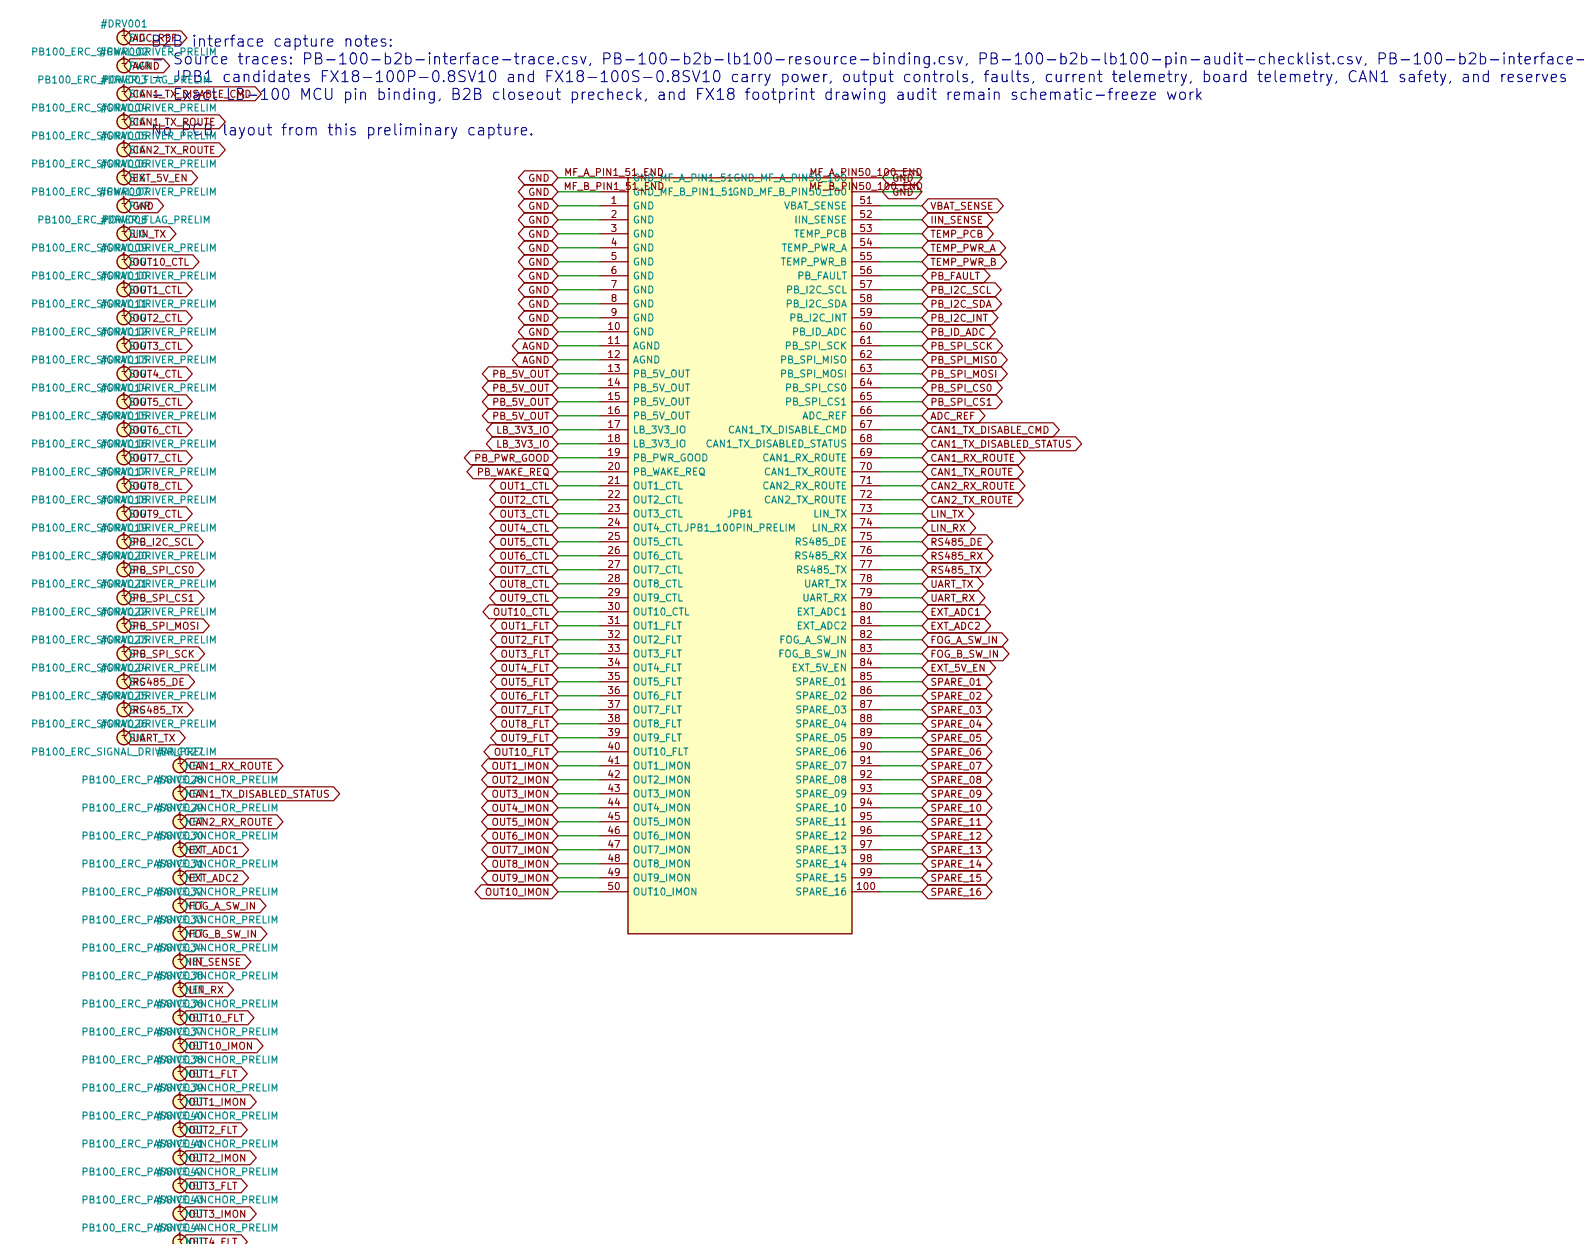
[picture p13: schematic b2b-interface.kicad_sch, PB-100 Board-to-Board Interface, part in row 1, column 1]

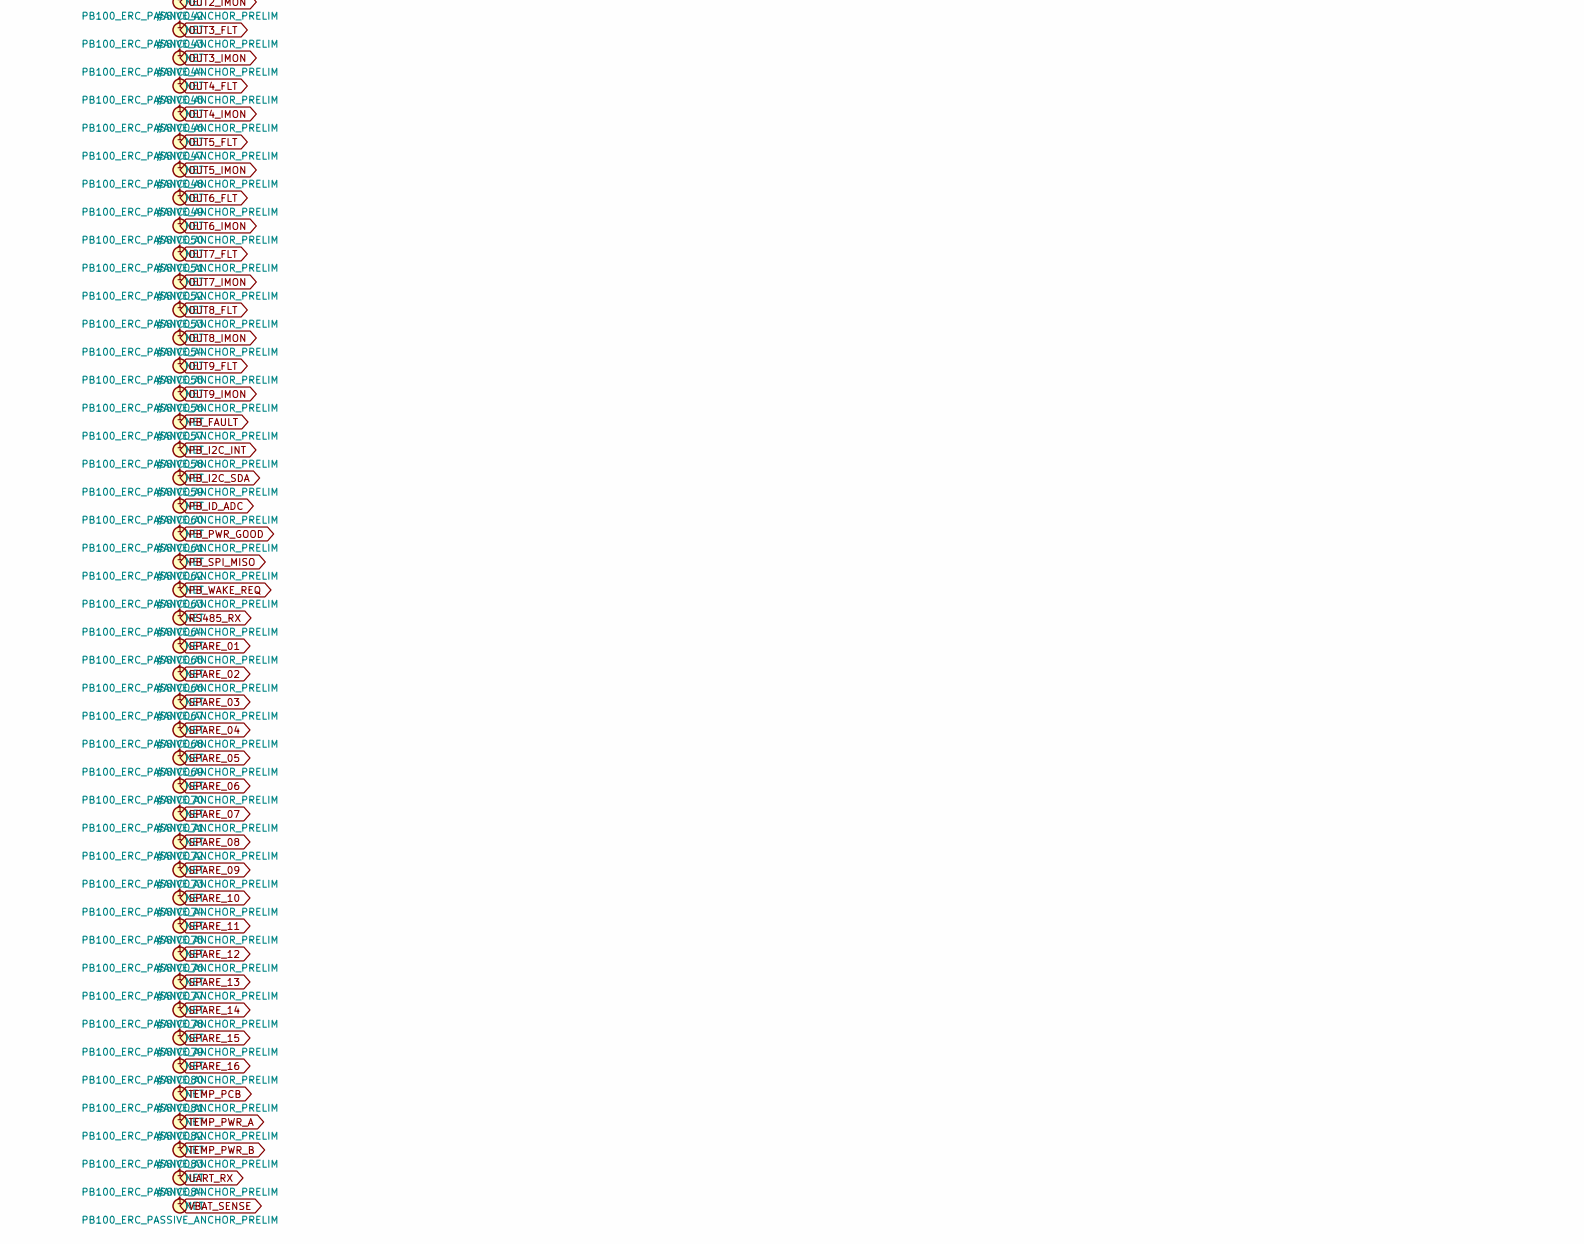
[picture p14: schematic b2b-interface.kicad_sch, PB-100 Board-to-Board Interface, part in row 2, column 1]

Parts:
JPB1: JPB1_100PIN_PRELIM; FX18-100P-0.8SV10_Hirose

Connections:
LB_3V3_IO: JPB1.17 (LB_3V3_IO), JPB1.18 (LB_3V3_IO); also elsewhere on the board
PB_5V_OUT: JPB1.13 (PB_5V_OUT), JPB1.14 (PB_5V_OUT), JPB1.15 (PB_5V_OUT), JPB1.16 (PB_5V_OUT); also elsewhere on the board

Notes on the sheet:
B2B interface capture notes: - Source traces: PB-100-b2b-interface-trace.csv, PB-100-b2b-lb100-resource-binding.csv, PB-100-b2b-lb100-pin-audit-checklist.csv, PB-100-b2b-interface-freeze-checklist.csv, PB-100-b2b-interface-closeout-precheck.csv, PB-100-b2b-pin-map.csv, PB-100-b2b-pin-budget.csv - J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

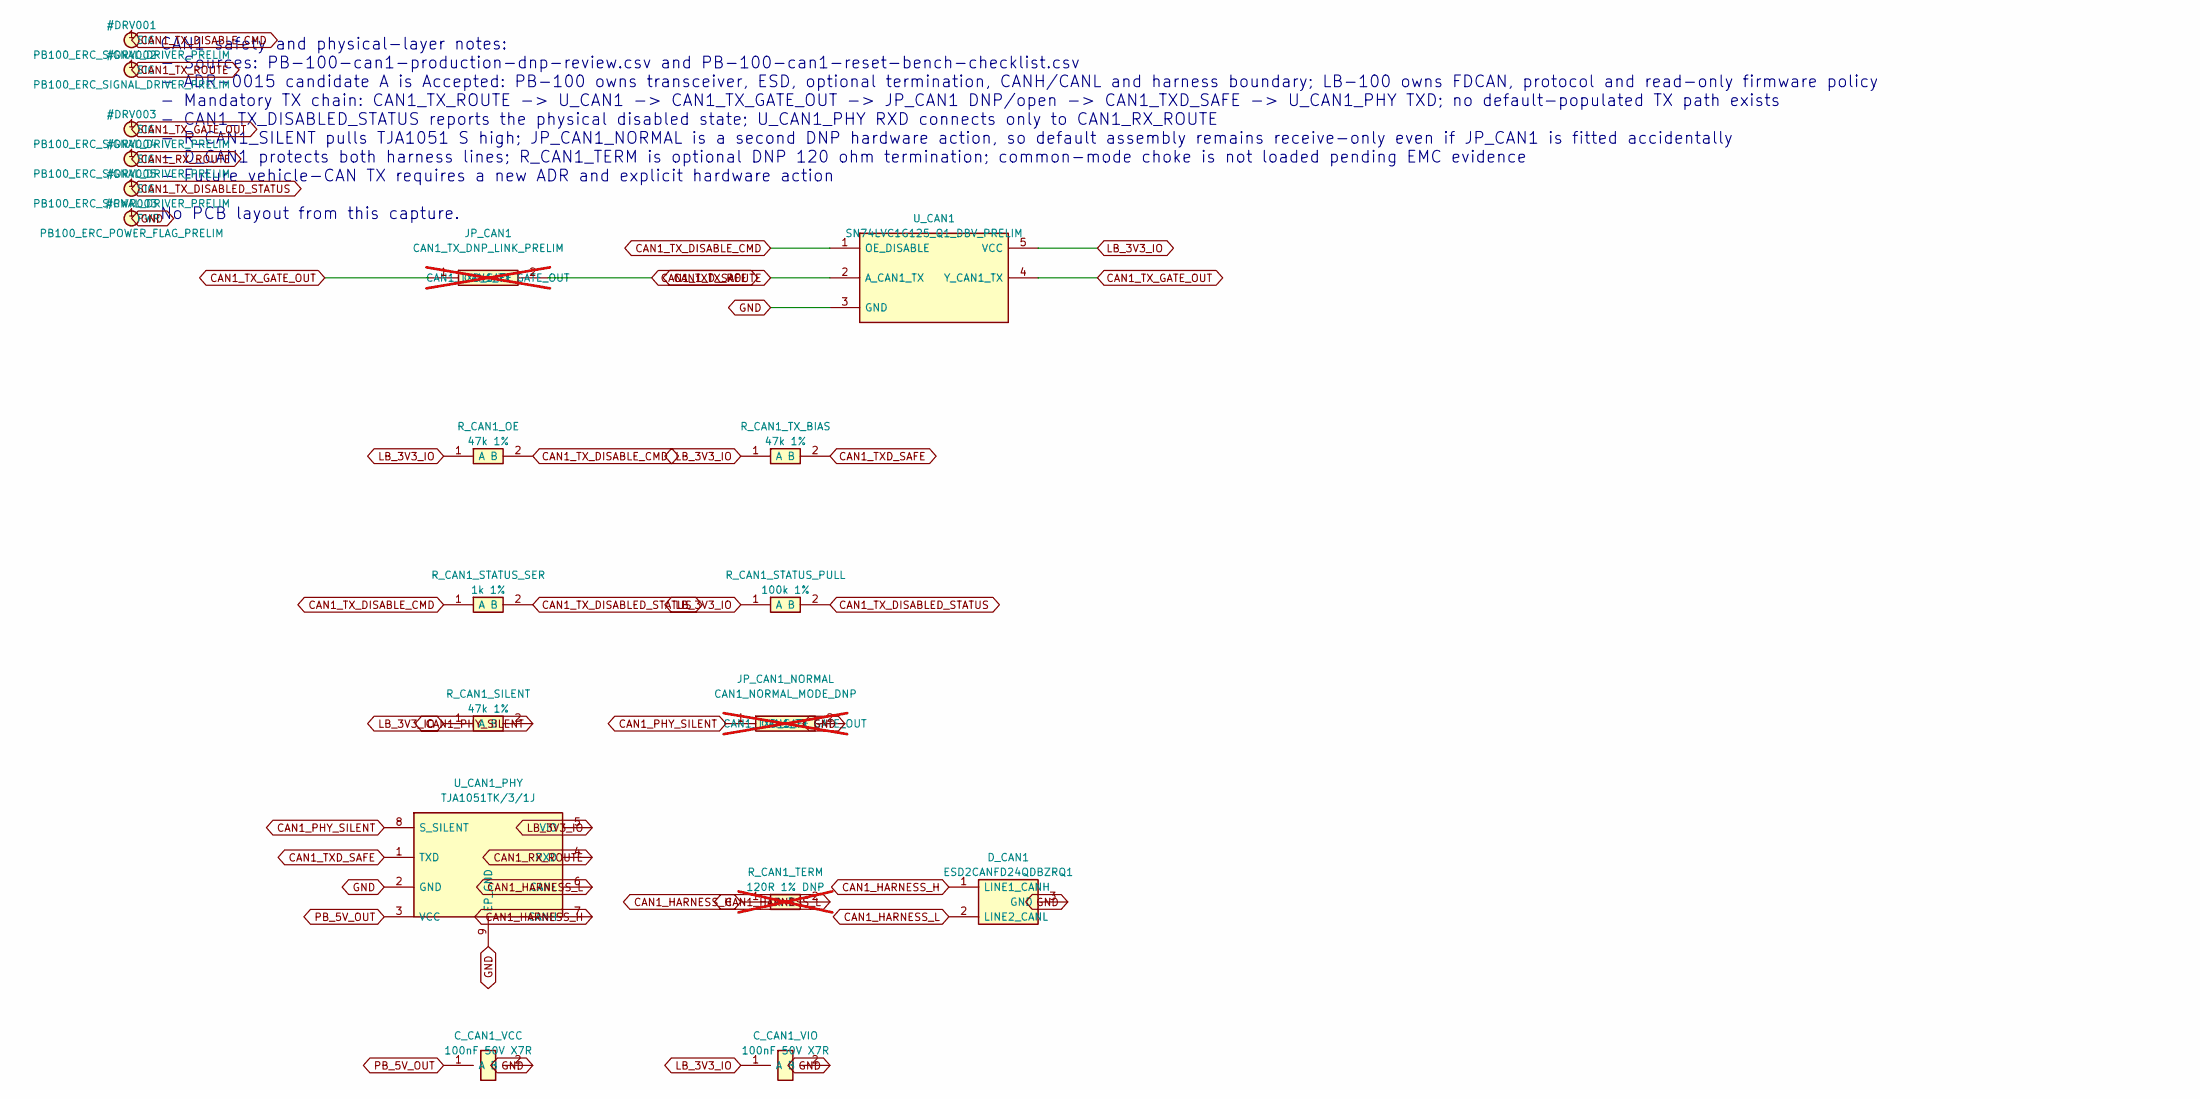
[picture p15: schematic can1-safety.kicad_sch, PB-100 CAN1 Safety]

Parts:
C_CAN1_VCC, C_CAN1_VIO: 100nF 50V X7R; C0402
D_CAN1: ESD2CANFD24QDBZRQ1; SOT-23-3_DBZ_TI
JP_CAN1: CAN1_TX_DNP_LINK_PRELIM; R0603_DNP_LINK_1608Metric; not fitted
JP_CAN1_NORMAL: CAN1_NORMAL_MODE_DNP; R0603_DNP_LINK_1608Metric; not fitted
R_CAN1_OE, R_CAN1_SILENT, R_CAN1_TX_BIAS: 47k 1%; R0402
R_CAN1_STATUS_PULL: 100k 1%; R0402
R_CAN1_STATUS_SER: 1k 1%; R0402
R_CAN1_TERM: 120R 1% DNP; R0603_DNP_LINK_1608Metric; not fitted
U_CAN1: SN74LVC1G125_Q1_DBV_PRELIM; SOT-23-5_DBV_TI
U_CAN1_PHY: TJA1051TK/3/1J; HVSON-8_L3.0-W3.0-P0.65-BL-EP

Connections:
CAN1_HARNESS_H: D_CAN1.1 (LINE1_CANH), R_CAN1_TERM.1 (A), U_CAN1_PHY.7 (CANH)
CAN1_HARNESS_L: D_CAN1.2 (LINE2_CANL), R_CAN1_TERM.2 (B), U_CAN1_PHY.6 (CANL)
CAN1_PHY_SILENT: JP_CAN1_NORMAL.1 (CAN1_TX_GATE_OUT), R_CAN1_SILENT.2 (B), U_CAN1_PHY.8 (S_SILENT)
CAN1_TXD_SAFE: JP_CAN1.2 (CAN1_TXD_SAFE), R_CAN1_TX_BIAS.2 (B), U_CAN1_PHY.1 (TXD)
LB_3V3_IO: C_CAN1_VIO.1 (A), R_CAN1_OE.1 (A), R_CAN1_SILENT.1 (A), R_CAN1_STATUS_PULL.1 (A), R_CAN1_TX_BIAS.1 (A), U_CAN1.5 (VCC), U_CAN1_PHY.5 (VIO); also elsewhere on the board
PB_5V_OUT: C_CAN1_VCC.1 (A), U_CAN1_PHY.3 (VCC); also elsewhere on the board

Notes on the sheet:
CAN1 safety and physical-layer notes: - Sources: PB-100-can1-production-dnp-review.csv and PB-100-can1-reset-bench-checklist.csv - ADR-0015 candidate A is Accepted: PB-100 owns transceiver, ESD, optional termination, CANH/CANL and harness boundary; LB-100 owns FDCAN, protocol and read-only firmware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

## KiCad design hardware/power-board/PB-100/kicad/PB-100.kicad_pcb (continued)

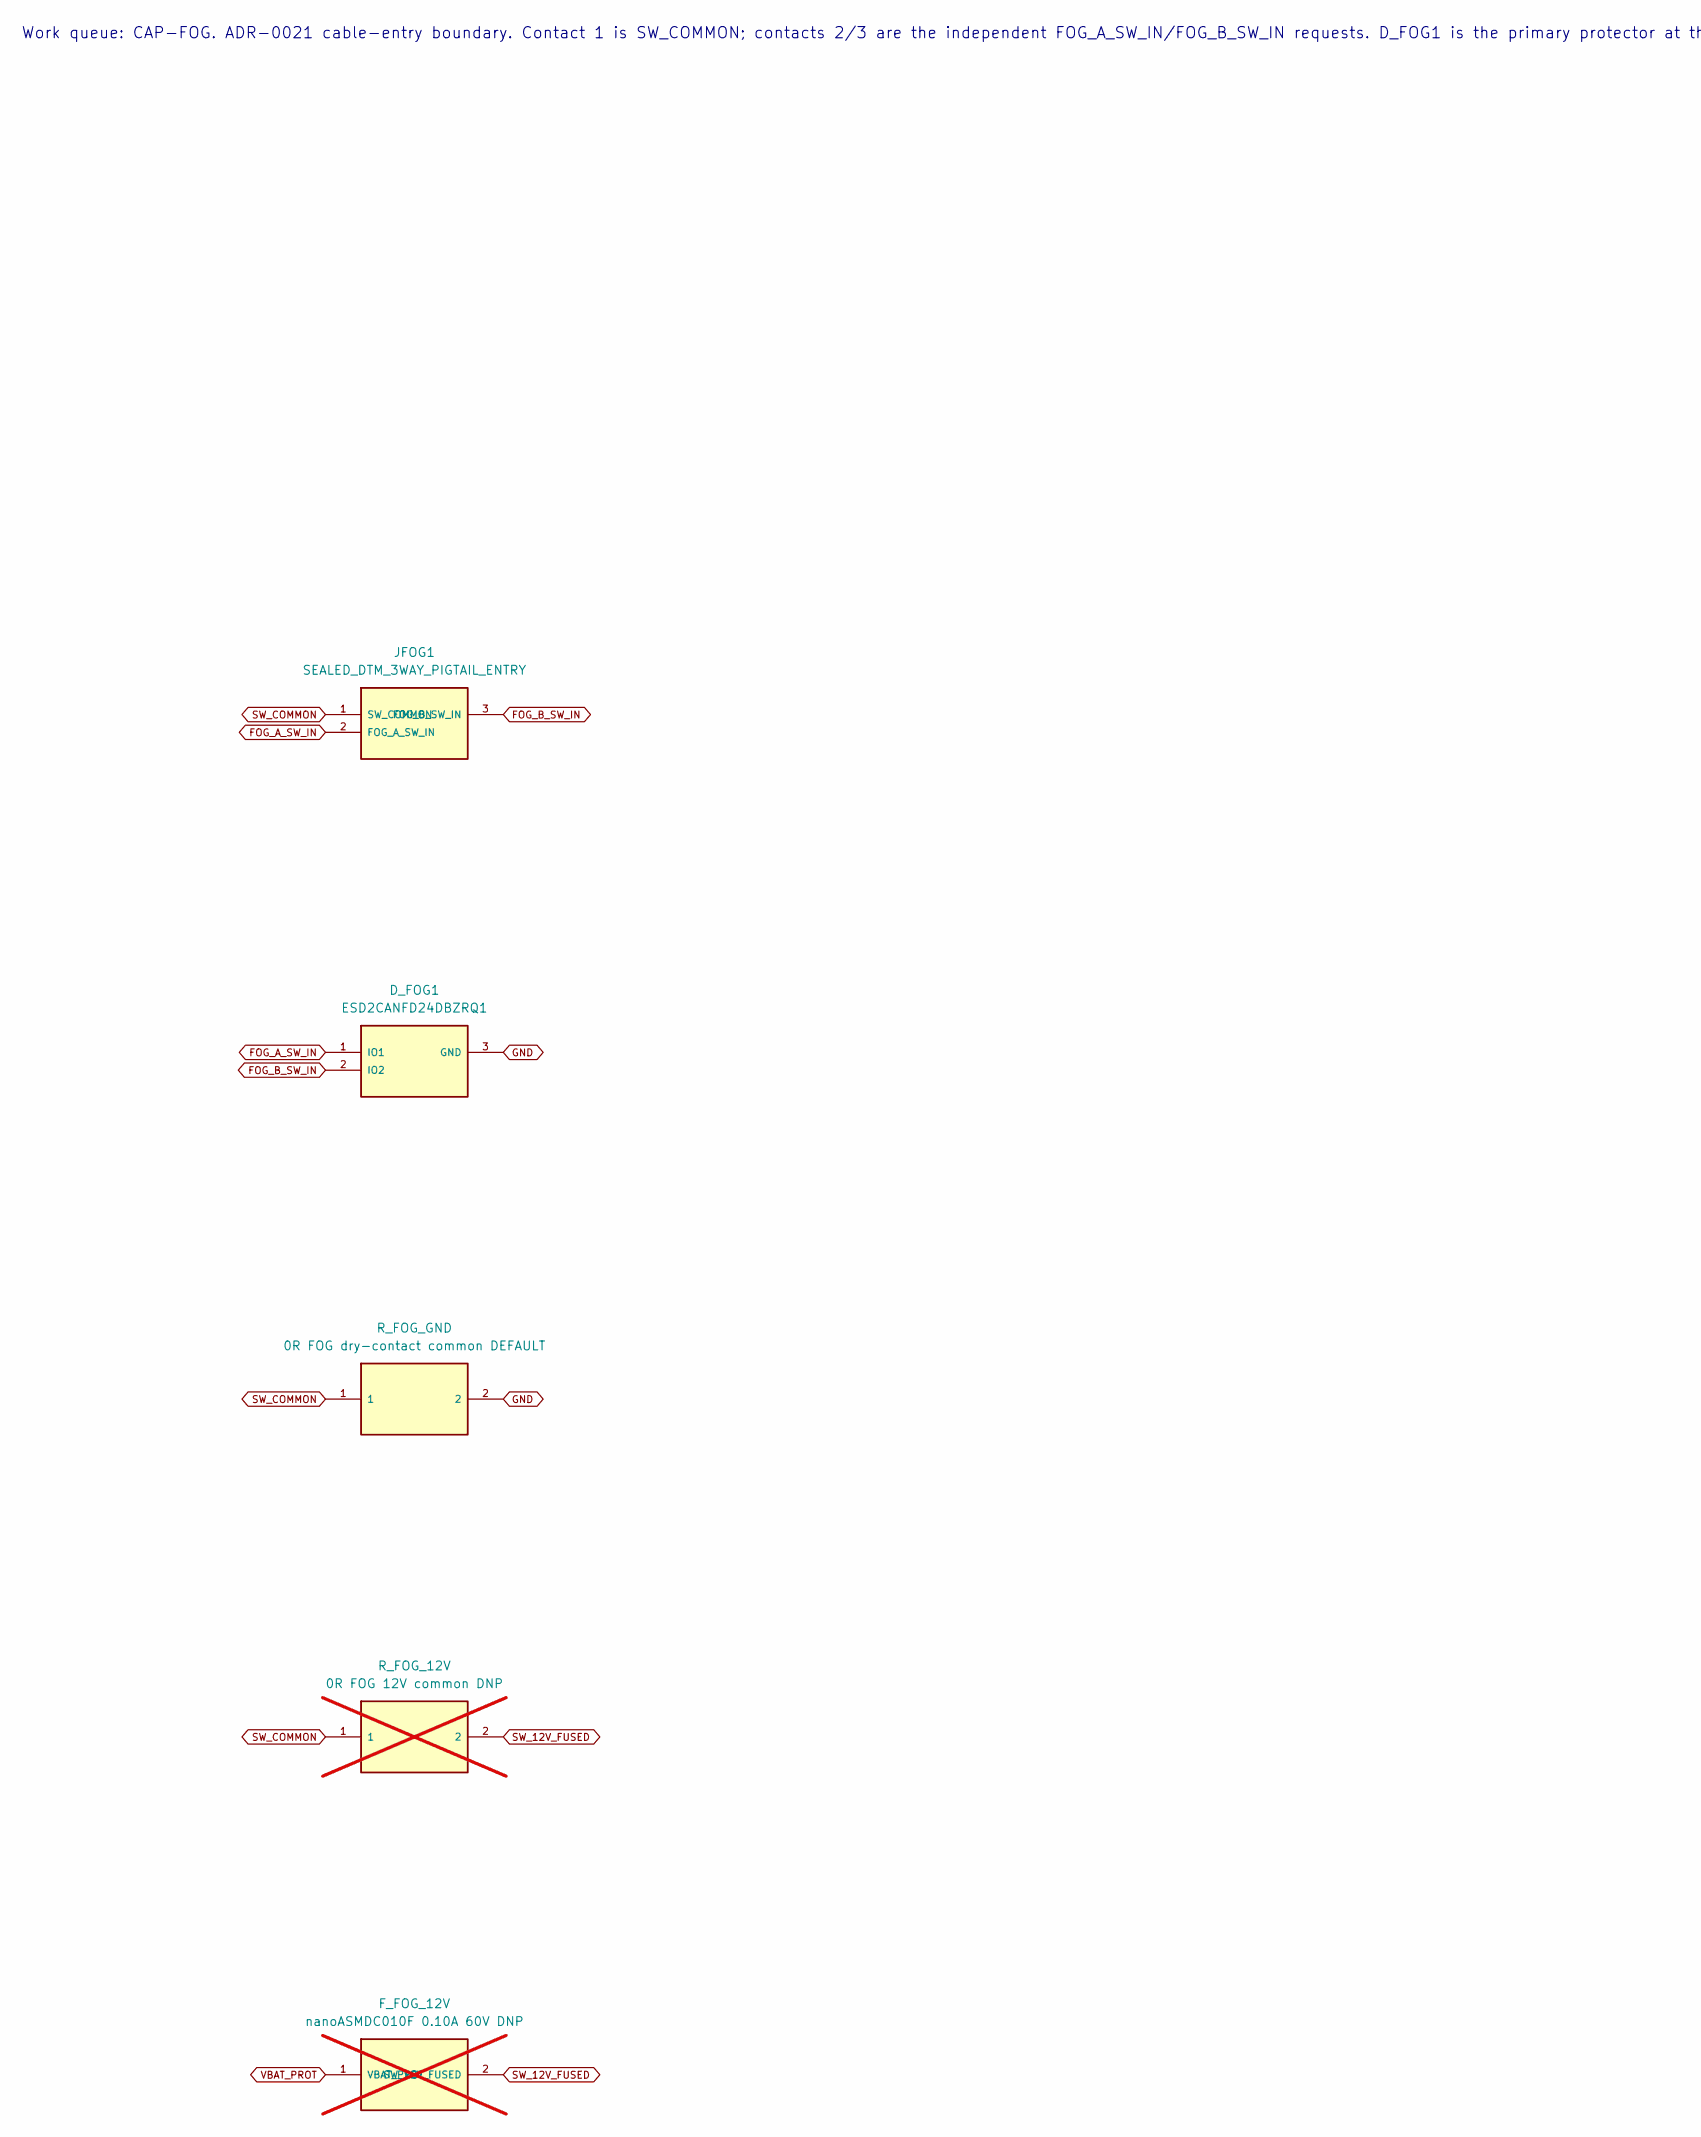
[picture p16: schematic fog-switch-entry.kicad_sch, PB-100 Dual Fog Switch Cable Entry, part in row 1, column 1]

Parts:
D_FOG1: ESD2CANFD24DBZRQ1; SOT-23-3_DBZ_TI
F_FOG_12V: nanoASMDC010F 0.10A 60V DNP; PPTC_1206_3216Metric; not fitted
JFOG1: SEALED_DTM_3WAY_PIGTAIL_ENTRY; FOG_PIGTAIL_1x03_P3.50mm
R_FOG_12V: 0R FOG 12V common DNP; R0603_DNP_LINK_1608Metric; not fitted
R_FOG_GND: 0R FOG dry-contact common DEFAULT; R0603_DNP_LINK_1608Metric

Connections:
SW_12V_FUSED: F_FOG_12V.2 (SW_12V_FUSED), R_FOG_12V.2
SW_COMMON: JFOG1.1 (SW_COMMON), R_FOG_12V.1, R_FOG_GND.1
VBAT_PROT: F_FOG_12V.1 (VBAT_PROT); also elsewhere on the board

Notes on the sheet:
Work queue: CAP-FOG. ADR-0021 cable-entry boundary. Contact 1 is SW_COMMON; contacts 2/3 are the independent FOG_A_SW_IN/FOG_B_SW_IN requests. D_FOG1 is the primary protector at the PB entry. R_FOG_GND is fitted for the default dry-contact assembly. R_FOG_12V and F_FOG_12V are mutually exclusive DN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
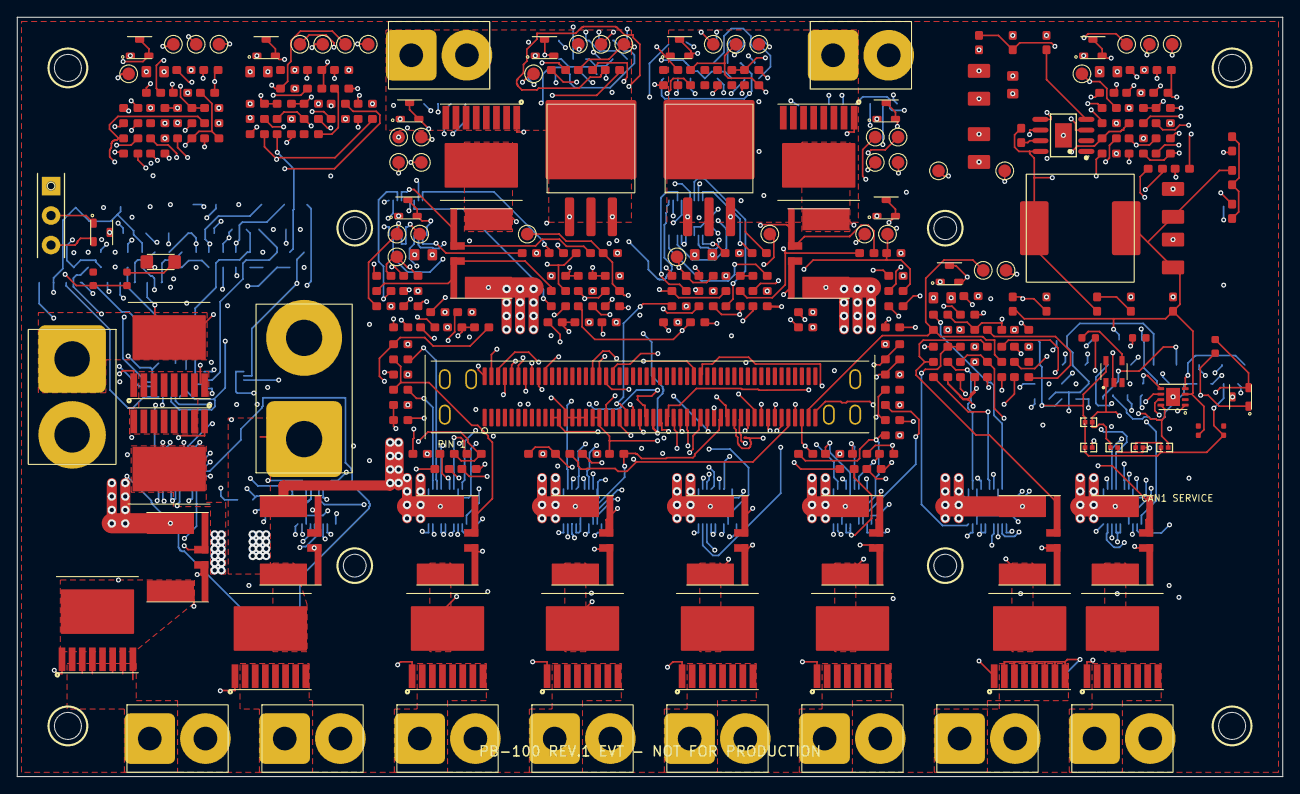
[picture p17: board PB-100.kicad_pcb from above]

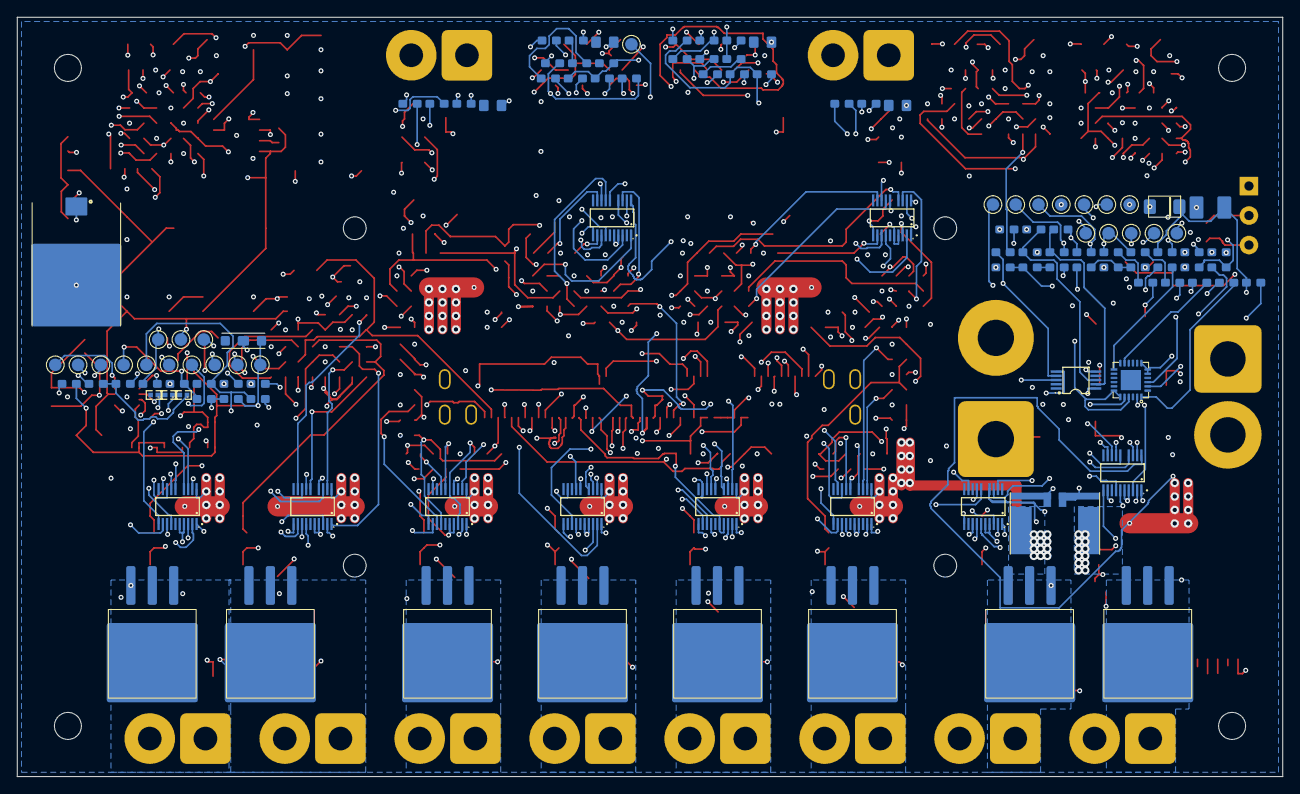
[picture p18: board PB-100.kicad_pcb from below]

Board: 8 copper layers, 150.0 x 90.0 mm, 422 parts (118 on the bottom side), 260 nets.

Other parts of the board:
H1, H2, H3, H4: LOCAL M3 NPTH; MountingHole_3.2mm
H5, H6, H7, H8: STACK M2.5 NPTH; MountingHole_2.7mm

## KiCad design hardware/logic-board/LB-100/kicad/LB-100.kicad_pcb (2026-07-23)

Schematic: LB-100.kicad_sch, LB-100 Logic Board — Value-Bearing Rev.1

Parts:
C1: 1uF 10V X7R; R_C_0603_1608Metric
C2, C4, C28: 1uF 6.3V X7R; R_C_0603_1608Metric
C3: 10uF 6.3V X7R; R_C_0805_2012Metric
C5, C8, C15, C16, C17, C18, C19, C20, C21, C22, C23, C24, C25, C26, C27, C29, C30: 100nF 6.3V X7R; R_C_0603_1608Metric
C6, C7: 2.2uF 6.3V X7R; R_C_0603_1608Metric
C9, C10: 18pF 50V C0G; R_C_0603_1608Metric
C11, C12: 8.2pF 50V C0G; R_C_0603_1608Metric
C13, C14: 1nF 50V C0G; R_C_0603_1608Metric
C31: 100nF 6.3V X7R BMI270 VDDIO; R_C_0603_1608Metric
C32: 100nF 6.3V X7R U15; R_C_0603_1608Metric
C33: 100nF 6.3V X7R U16; R_C_0603_1608Metric
C34: 100nF 6.3V X7R U17; R_C_0603_1608Metric
C35: 47nF 50V X7R FOG_A filter; R_C_0603_1608Metric
C36: 47nF 50V X7R FOG_B filter; R_C_0603_1608Metric
C37: 100nF 6.3V X7R U18; R_C_0603_1608Metric
C38: 100nF 6.3V X7R U19; R_C_0603_1608Metric
D19, D20: BZT52H-B4V3-Q; SOD-123F_L2.6-W1.6
FB1: 600R@100MHz 0.2A; R_C_0603_1608Metric
JBT1: BACKUP_BATTERY_2V3_TO_3V6_DNP; PinHeader_1x02_P2.54mm_Vertical; not fitted
JDBG1: SWD_2x3_1.27mm; PinHeader_2x03_P1.27mm_Vertical
JFB1: AFC07-S24ECA-00; FPC-SMD_AFC07-S24ECA-00
JPB1: FX18-100S-0.8SV10; FX18-100S-0.8SV10_Hirose
JSD1: TF-015; TF-SMD_TF-015
Q18, Q19: BC847BQ-7-F 12V OPTION; SOT-23-3_DBZ_TI; not fitted
R1: 100k 1%; R_C_0603_1608Metric
R2, R3, R13, R14, R15, R16: 0R; R_C_0603_1608Metric
R4, R5, R12: 10k 1%; R_C_0603_1608Metric
R6, R7: 2.2k 1%; R_C_0603_1608Metric
R8: 4.7k 1%; R_C_0603_1608Metric
R9: 10k 1% switched reset pull-up; R_C_0603_1608Metric
R10, R11: 47k 1%; R_C_0603_1608Metric
R17: 0R single-point analog return; R_C_0603_1608Metric
R18, R19: 22k 1% switched UART idle clamp; R_C_0603_1608Metric
R20, R22: 100k 1% MCU UART idle pull-up; R_C_0603_1608Metric
R21: 100k 1% reset default assert; R_C_0603_1608Metric
R23: 4.7k 1% FOG_A dry-contact series; R_C_0603_1608Metric
R24: 47k 1% FOG_A 12V base DNP; R_C_0603_1608Metric; not fitted
R25: 100k 1% FOG_A base pull-down DNP; R_C_0603_1608Metric; not fitted
R26: 47k 1% FOG_A pull-up; R_C_0603_1608Metric
R27: 4.7k 1% FOG_B dry-contact series; R_C_0603_1608Metric
R28: 47k 1% FOG_B 12V base DNP; R_C_0603_1608Metric; not fitted
R29: 100k 1% FOG_B base pull-down DNP; R_C_0603_1608Metric; not fitted
R30: 47k 1% FOG_B pull-up; R_C_0603_1608Metric
TP1: E73_SWDIO; TestPoint_SMD_1.2mm
TP2: E73_SWDCLK; TestPoint_SMD_1.2mm
TP3: BLE_RESET_N; TestPoint_SMD_1.2mm
TP4: RADIO_SENSOR_3V3; TestPoint_SMD_1.2mm
TP5: GND; TestPoint_SMD_1.2mm
U1: STM32H563VIT6; LQFP-100_L14.0-W14.0-P0.50-LS16.0-BL
U2: XC6220B331MR-G; SOT-25_L3.0-W1.6-P0.95-LS2.8-TL
U3: TCA9539QPWRQ1; TSSOP-24_4.4x7.8mm_P0.65mm
U4: TJA1051TK/3,118; HVSON-8_L3.0-W3.0-P0.65-BL-EP; not fitted
U5: TJA1021T/20/CM,118; SOIC-8_L4.9-W3.9-P1.27-LS6.0-BL; not fitted
U6: SP3485EN-L/TR; SOIC-8_L5.0-W4.0-P1.27-LS6.0-BL; not fitted
U7: E73-2G4M08S1C; WIRELM-SMD_E73-2G4M08S1C
U8: FM24CL64B-GTR; SOIC-8_L4.9-W3.9-P1.27-LS6.0-BL
U9: DS3231MZ+TRL; SOIC-8_L4.9-W3.9-P1.27-LS6.0-BL
U10: BMI270; LGA-14_L3.0-W2.5-P0.50-BR
U11: VEML7700-TT; SENSOR-SMD_EML7700-TT
U12, U13: TPS22918TDBVRQ1; SOT-23-6_L2.9-W1.6-P0.95-LS2.8-BL
U14, U18, U19: SN74LVC1G17QDBVRQ1; SOT-25_L3.0-W1.6-P0.95-LS2.8-TL
U15, U16, U17: SN74LVC1G125QDBVRQ1; SOT-25_L3.0-W1.6-P0.95-LS2.8-TL
Y1: ABM8AIG-25.000MHZ-12-2Z-T3; Crystal_SMD_3225-4Pin
Y2: ABS07AIG-32.768kHz-7-T; Crystal_SMD_3215-2Pin

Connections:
ADC_REF: C28.1, C29.1, JPB1.66 (ADC_REF), R16.2, U1.21 (VREF+)
AGND: C4.2, C5.2, C28.2, C29.2, JPB1.11 (AGND), JPB1.12 (AGND), R17.1, U1.19 (VSSA), U1.20 (VREF-)
BACKUP_AON: JBT1.1 (BACKUP_AON), U9.6 (VBAT)
BLE_RESET_N: R9.2, TP3.1 (BLE_RESET_N), U7.26 (RESET), U17.4 (Y)
BLE_RESET_N_MCU: R21.1, U1.97 (PE0), U17.2 (A)
BLE_UART_RX_MODULE: R18.1, U7.22 (P0.07), U15.4 (Y)
BLE_UART_TX_MODULE: R19.1, U7.20 (P0.12), U16.2 (A)
BOOT0: R5.1, U1.94 (BOOT0)
CAN1_RX_ROUTE: JPB1.69 (CAN1_RX_ROUTE), U1.95 (PB8)
CAN1_TX_DISABLED_STATUS: JPB1.68 (CAN1_TX_DISABLED_STATUS), U1.58 (PD11)
CAN1_TX_DISABLE_CMD: JPB1.67 (CAN1_TX_DISABLE_CMD), U1.85 (PD4)
CAN1_TX_ROUTE: JPB1.70 (CAN1_TX_ROUTE), U1.96 (PB9)
CAN2_RX_ROUTE: JPB1.71 (CAN2_RX_ROUTE), U1.51 (PB12), U4.4 (RXD)
CAN2_TX_ROUTE: JPB1.72 (CAN2_TX_ROUTE), U1.52 (PB13), U4.1 (TXD)
CH_LED_1: JFB1.10 (CH_LED_1), U3.4 (P00)
CH_LED_2: JFB1.11 (CH_LED_2), U3.5 (P01)
CH_LED_3: JFB1.12 (CH_LED_3), U3.6 (P02)
CH_LED_4: JFB1.13 (CH_LED_4), U3.7 (P03)
CH_LED_5: JFB1.14 (CH_LED_5), U3.8 (P04)
CH_LED_6: JFB1.15 (CH_LED_6), U3.9 (P05)
CH_LED_7: JFB1.16 (CH_LED_7), U3.10 (P06)
CH_LED_8: JFB1.17 (CH_LED_8), U3.11 (P07)
CH_LED_9: JFB1.18 (CH_LED_9), U3.13 (P10)
CH_LED_10: JFB1.19 (CH_LED_10), U3.14 (P11)
E73_SWDCLK: TP2.1 (E73_SWDCLK), U7.39 (SWDCLK)
E73_SWDIO: TP1.1 (E73_SWDIO), U7.37 (SWDIO)
EXT_5V_EN: JPB1.84 (EXT_5V_EN), U1.69 (PA10)
EXT_ADC1: JPB1.80 (EXT_ADC1), U1.64 (PC7)
EXT_ADC2: JPB1.81 (EXT_ADC2), U1.65 (PC8)
FB_3V3_OR_IO: JFB1.2 (FB_3V3_OR_IO), R3.2
FOG_A_12V_BASE: Q18.1 (B), R24.2, R25.1
FOG_A_FILTERED: C35.1, D19.1 (K), Q18.3 (C), R23.2, R26.2, U18.2 (A)
FOG_A_SW_IN: JPB1.82 (FOG_A_SW_IN), R23.1, R24.1
FOG_A_SW_IN_MCU: U1.67 (PA8), U18.4 (Y)
FOG_B_12V_BASE: Q19.1 (B), R28.2, R29.1
FOG_B_FILTERED: C36.1, D20.1 (K), Q19.3 (C), R27.2, R30.2, U19.2 (A)
FOG_B_SW_IN: JPB1.83 (FOG_B_SW_IN), R27.1, R28.1
FOG_B_SW_IN_MCU: U1.68 (PA9), U19.4 (Y)
GND: C1.2, C2.2, C3.2, C6.2, C7.2, C8.2, C9.2, C10.2, C11.2, C12.2, C13.2, C14.2, C15.2, C16.2, C17.2, C18.2, C19.2, C20.2, C21.2, C22.2, C23.2, C24.2, C25.2, C26.2, C27.2, C30.2, C31.2, C32.2, C33.2, C34.2, C35.2, C36.2, C37.2, C38.2, D19.2 (A), D20.2 (A), JBT1.2 (GND), JDBG1.3 (GND), JDBG1.5 (GND), JFB1.1 (GND), JFB1.3 (GND), JFB1.25 (SHIELD_A), JFB1.26 (SHIELD_B), JPB1.1 (GND), JPB1.2 (GND), JPB1.3 (GND), JPB1.4 (GND), JPB1.5 (GND), JPB1.6 (GND), JPB1.7 (GND), JPB1.8 (GND), JPB1.9 (GND), JPB1.10 (GND), JPB1.MF_A_PIN1_51_END, JPB1.MF_A_PIN50_100_END, JPB1.MF_B_PIN1_51_END, JPB1.MF_B_PIN50_100_END, JSD1.6 (VSS), JSD1.10 (SHELL1), JSD1.11 (SHELL2), JSD1.12 (SHELL3), JSD1.13 (SHELL4), Q18.2 (E), Q19.2 (E), R1.2, R5.2, R17.2, R21.2, R25.2, R29.2, TP5.1 (GND), U1.10 (VSS), U1.27 (VSS), U1.49 (VSS), U1.74 (VSS), U1.99 (VSS), U2.2 (VSS), U3.2 (A1), U3.12 (GND), U3.21 (A0), U4.2 (GND), U4.9 (EP), U5.2 (SLP_N), U5.5 (GND), U6.5 (GND), U7.5 (GND), U7.21 (GND), U7.24 (GND), U8.1 (A0), U8.2 (A1), U8.3 (A2), U8.4 (VSS), U8.7 (WP), U9.5 (GND), U10.1 (SDO), U10.6 (GNDIO), U10.7 (GND), U11.3 (GND), U12.2 (GND), U13.2 (GND), U14.3 (GND), U15.1 (OE_N), U15.3 (GND), U16.1 (OE_N), U16.3 (GND), U17.1 (OE_N), U17.3 (GND), U18.3 (GND), U19.3 (GND), Y1.2 (GND1), Y1.4 (GND2)
IIN_SENSE: JPB1.52 (IIN_SENSE), U1.32 (PA7)
IMU_INT1: U3.18 (P15), U10.4 (INT1)
IOX_INT_N: R8.2, U1.54 (PB15), U3.1 (INT_N)
LB_3V3_ANALOG: C4.1, C5.1, FB1.2, R16.1, U1.22 (VDDA)
LB_3V3_IO: C30.1, C31.1, C37.1, C38.1, JPB1.17 (LB_3V3_IO), JPB1.18 (LB_3V3_IO), R2.2, R6.1, R7.1, R26.1, R30.1, U10.5 (VDDIO), U10.12 (CSB), U11.2 (VDD), U14.5 (VCC), U18.5 (VCC), U19.5 (VCC)
LB_3V3_MAIN: C2.1, C3.1, C15.1, C16.1, C17.1, C18.1, C19.1, C20.1, C21.1, FB1.1, JDBG1.1 (VTREF), R2.1, R3.1, R4.1, R8.1, R20.1, R22.1, U1.6 (VBAT), U1.11 (VDD), U1.28 (VDD), U1.50 (VDD), U1.73 (VDDUSB), U1.75 (VDD), U1.100 (VDD), U2.5 (VOUT), U3.24 (VCC), U4.5 (VIO), U4.8 (S), U5.3 (WAKE_N), U6.8 (VCC), U8.8 (VDD), U9.2 (VCC), U12.1 (VIN), U13.1 (VIN)
LIN_RX: JPB1.74 (LIN_RX), U1.87 (PD6), U5.1 (RXD)
LIN_TX: JPB1.73 (LIN_TX), U1.86 (PD5), U5.4 (TXD)
MCU_HSE_IN: C9.1, U1.12 (PH0-OSC_IN), Y1.1 (XIN)
MCU_HSE_OUT: C10.1, U1.13 (PH1-OSC_OUT), Y1.3 (XOUT)
MCU_LSE_IN: C11.1, U1.8 (PC14-OSC32_IN), Y2.1 (XIN)
MCU_LSE_OUT: C12.1, U1.9 (PC15-OSC32_OUT), Y2.2 (XOUT)
MICROSD_3V3: C26.1, C27.1, JSD1.4 (VDD), R10.1, R11.1, R12.1, U12.5 (QOD), U12.6 (VOUT)
MICROSD_3V3_CT: C13.1, U12.4 (CT)
MICROSD_CARD_DETECT: JSD1.9 (CARD_DETECT), U3.17 (P14)
MICROSD_CS_N: JSD1.2 (CD_DAT3), R12.2, U1.80 (PC12)
MICROSD_DAT1: JSD1.8 (DAT1), R10.2
MICROSD_DAT2: JSD1.1 (DAT2), R11.2
MICROSD_PWR_EN: U1.81 (PD0), U12.3 (ON)
NRST: C8.1, R4.2, R15.1, U1.14 (NRST), U3.3 (RESET_N), U9.4 (RST_N)
OLED_RST_OR_INT_DNP: JFB1.24 (OLED_RST_OR_INT_DNP), U3.20 (P17)
OLED_SCL: JFB1.22 (OLED_SCL), R13.2
OLED_SDA: JFB1.23 (OLED_SDA), R14.2
OUT1_CTL: JPB1.21 (OUT1_CTL), U1.4 (PE5)
OUT1_FLT: JPB1.31 (OUT1_FLT), U1.1 (PE2)
OUT1_IMON: JPB1.41 (OUT1_IMON), U1.15 (PC0)
OUT2_CTL: JPB1.22 (OUT2_CTL), U1.5 (PE6)
OUT2_FLT: JPB1.32 (OUT2_FLT), U1.2 (PE3)
OUT2_IMON: JPB1.42 (OUT2_IMON), U1.16 (PC1)
OUT3_CTL: JPB1.23 (OUT3_CTL), U1.40 (PE9)
OUT3_FLT: JPB1.33 (OUT3_FLT), U1.3 (PE4)
OUT3_IMON: JPB1.43 (OUT3_IMON), U1.17 (PC2)
OUT4_CTL: JPB1.24 (OUT4_CTL), U1.42 (PE11)
OUT4_FLT: JPB1.34 (OUT4_FLT), U1.38 (PE7)
OUT4_IMON: JPB1.44 (OUT4_IMON), U1.18 (PC3)
OUT5_CTL: JPB1.25 (OUT5_CTL), U1.44 (PE13)
OUT5_FLT: JPB1.35 (OUT5_FLT), U1.39 (PE8)
OUT5_IMON: JPB1.45 (OUT5_IMON), U1.23 (PA0)
OUT6_CTL: JPB1.26 (OUT6_CTL), U1.45 (PE14)
OUT6_FLT: JPB1.36 (OUT6_FLT), U1.41 (PE10)
OUT6_IMON: JPB1.46 (OUT6_IMON), U1.24 (PA1)
OUT7_CTL: JPB1.27 (OUT7_CTL), U1.59 (PD12)
OUT7_FLT: JPB1.37 (OUT7_FLT), U1.43 (PE12)
OUT7_IMON: JPB1.47 (OUT7_IMON), U1.25 (PA2)
OUT8_CTL: JPB1.28 (OUT8_CTL), U1.60 (PD13)
OUT8_FLT: JPB1.38 (OUT8_FLT), U1.46 (PE15)
OUT8_IMON: JPB1.48 (OUT8_IMON), U1.26 (PA3)
OUT9_CTL: JPB1.29 (OUT9_CTL), U1.61 (PD14)
OUT9_FLT: JPB1.39 (OUT9_FLT), U1.63 (PC6)
OUT9_IMON: JPB1.49 (OUT9_IMON), U1.29 (PA4)
OUT10_CTL: JPB1.30 (OUT10_CTL), U1.62 (PD15)
OUT10_FLT: JPB1.40 (OUT10_FLT), U1.66 (PC9)
OUT10_IMON: JPB1.50 (OUT10_IMON), U1.30 (PA5)
PB_5V_OUT: C1.1, JPB1.13 (PB_5V_OUT), JPB1.14 (PB_5V_OUT), JPB1.15 (PB_5V_OUT), JPB1.16 (PB_5V_OUT), U2.1 (VIN), U4.3 (VCC)
PB_FAULT: JPB1.56 (PB_FAULT), U1.84 (PD3)
PB_I2C_INT: JPB1.59 (PB_I2C_INT), U1.47 (PB10)
PB_I2C_SCL: JPB1.57 (PB_I2C_SCL), R6.2, R13.1, U1.92 (PB6), U3.22 (SCL), U8.6 (SCL), U9.8 (SCL), U10.13 (SCL), U11.1 (SCL)
PB_I2C_SDA: JPB1.58 (PB_I2C_SDA), R7.2, R14.1, U1.93 (PB7), U3.23 (SDA), U8.5 (SDA), U9.7 (SDA), U10.14 (SDA), U11.4 (SDA)
PB_ID_ADC: JPB1.60 (PB_ID_ADC), U1.36 (PB1)
PB_PWR_GOOD: JPB1.19 (PB_PWR_GOOD), R1.1, U1.83 (PD2), U2.3 (CE)
PB_SPI_CS0: JPB1.64 (PB_SPI_CS0), U1.77 (PA15)
PB_SPI_CS1: JPB1.65 (PB_SPI_CS1), U1.37 (PB2)
PB_SPI_MISO: JPB1.62 (PB_SPI_MISO), JSD1.7 (DAT0), U1.90 (PB4)
PB_SPI_MOSI: JPB1.63 (PB_SPI_MOSI), JSD1.3 (CMD), U1.91 (PB5)
PB_SPI_SCK: JDBG1.6 (SWO), JPB1.61 (PB_SPI_SCK), JSD1.5 (CLK), U1.89 (PB3-SWO)
PB_WAKE_REQ: JPB1.20 (PB_WAKE_REQ), U1.7 (PC13)
RADIO_SENSOR_3V3: C22.1, C23.1, C24.1, C25.1, C32.1, C33.1, C34.1, R9.1, R18.2, R19.2, TP4.1 (RADIO_SENSOR_3V3), U7.19 (VCC), U10.8 (VDD), U13.5 (QOD), U13.6 (VOUT), U15.5 (VCC), U16.5 (VCC), U17.5 (VCC)
RADIO_SENSOR_3V3_CT: C14.1, U13.4 (CT)
RADIO_SENSOR_EN: U1.82 (PD1), U13.3 (ON)
RESET_BTN: JFB1.21 (RESET_BTN), R15.2
RS485_DE: JPB1.75 (RS485_DE), U1.53 (PB14), U6.2 (RE_N), U6.3 (DE)
RS485_RX: JPB1.76 (RS485_RX), U1.56 (PD9), U6.1 (RO)
RS485_TX: JPB1.77 (RS485_TX), U1.55 (PD8), U6.4 (DI)
RTC_INT_N: U3.19 (P16), U9.3 (INT_SQW_N)
SERVICE_BTN: JFB1.20 (SERVICE_BTN), U3.16 (P13)
STATUS_RGB_DATA: JFB1.9 (STATUS_RGB_DATA), U1.88 (PD7)
SWCLK: JDBG1.4 (SWCLK), U1.76 (PA14-SWCLK)
SWDIO: JDBG1.2 (SWDIO), U1.72 (PA13-SWDIO)
TEMP_PCB: JPB1.53 (TEMP_PCB), U1.33 (PC4)
TEMP_PWR_A: JPB1.54 (TEMP_PWR_A), U1.34 (PC5)
TEMP_PWR_B: JPB1.55 (TEMP_PWR_B), U1.35 (PB0)
UART_RX: JPB1.79 (UART_RX), R20.2, U1.79 (PC11), U16.4 (Y)
UART_TX: JPB1.78 (UART_TX), R22.2, U1.78 (PC10), U15.2 (A)
USB_CC1: JFB1.6 (USB_CC1)
USB_CC2: JFB1.7 (USB_CC2)
USB_D_N: JFB1.5 (USB_D_N), U1.70 (PA11-USB_DM)
USB_D_P: JFB1.4 (USB_D_P), U1.71 (PA12-USB_DP)
USB_VBUS_DETECT_RAW: JFB1.8 (USB_VBUS_DETECT_RAW), U14.2 (A)
USB_VBUS_PRESENT: U1.57 (PD10), U14.4 (Y)
VBAT_SENSE: JPB1.51 (VBAT_SENSE), U1.31 (PA6)
VCAP1: C6.1, U1.48 (VCAP1)
VCAP2: C7.1, U1.98 (VCAP2)

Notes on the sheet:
LB-100 reviewed value-bearing Rev.1 capture. STM32H563VIT6 LQFP100; exact ST package positions; JPB1 100 signals plus four GND MF circuits; PB_5V_OUT 500 mA allocation with reviewed 229.2 mA sustained and 381.2 mA service-peak budgets including FB-100 worst-case indication; ADR-0015 CAN1 FDCAN/read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

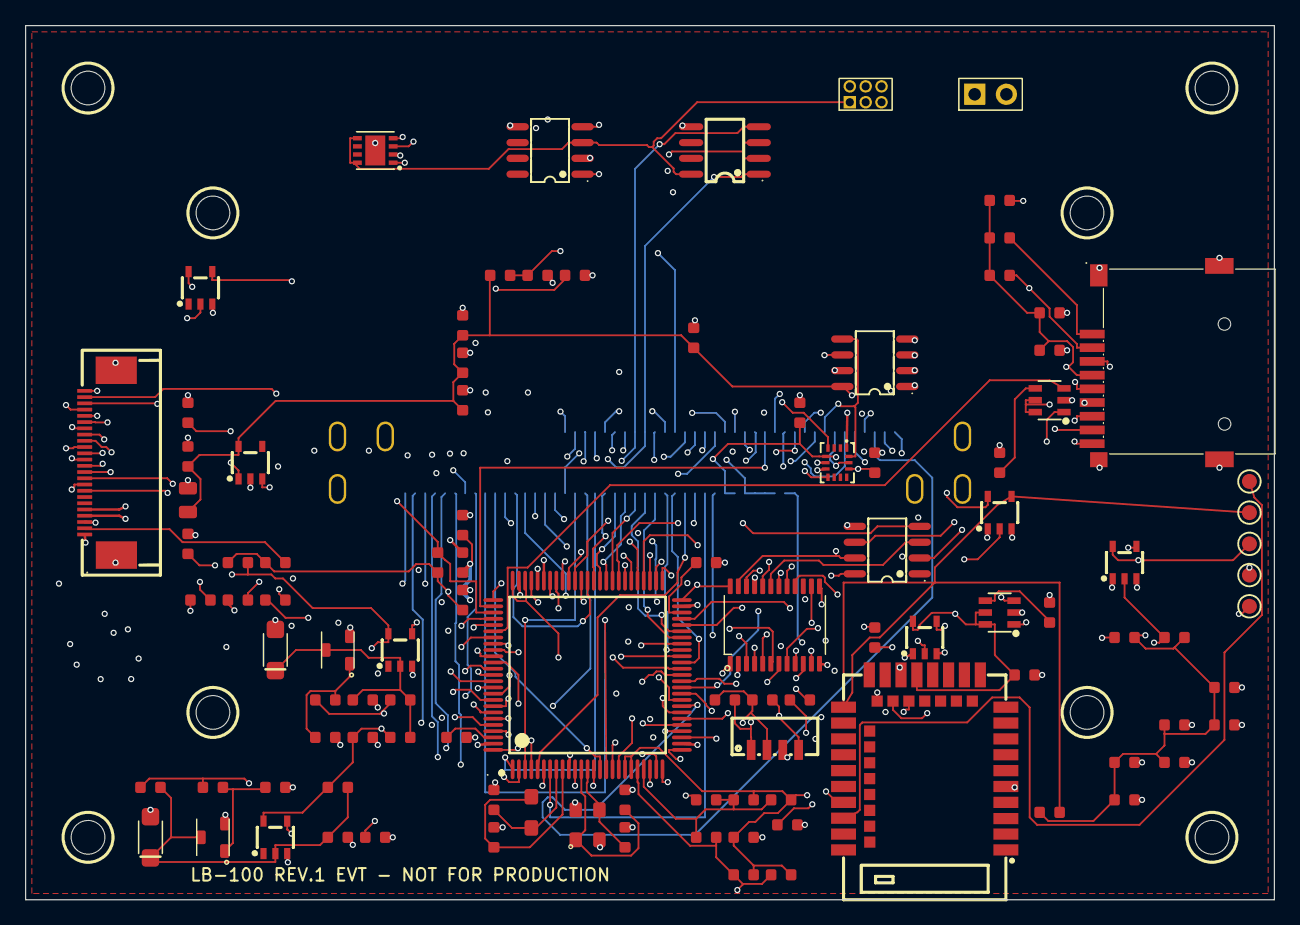
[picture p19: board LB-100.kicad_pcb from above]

Board: 6 copper layers, 100.0 x 70.0 mm, 112 parts (1 on the bottom side), 129 nets.

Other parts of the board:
H1, H2, H3, H4: LOCAL M2.5 NPTH; MountingHole_2.7mm_M2.5
H5, H6, H7, H8: STACK M2.5 NPTH; MountingHole_2.7mm_M2.5

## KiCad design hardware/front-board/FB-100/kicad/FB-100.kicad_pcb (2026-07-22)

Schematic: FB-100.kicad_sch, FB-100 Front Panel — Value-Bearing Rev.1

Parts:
C1: 100nF 16V X7R 10%; R_C_0603_1608Metric
C2: 1nF 1kV C0G; R_C_0603_1608Metric
C3, C4, C5: 1uF 6.3V X7R; R_C_0603_1608Metric
C6, C7: 100nF 6.3V X7R; R_C_0603_1608Metric
D1: USBLC6-2SC6; SOT-23-6_L2.9-W1.6-P0.95-LS2.8-BL
D2: 19-237/R6GHBHC-A01/2T; LED-ARRAY-SMD_4P-L1.6-W1.6-BL_1
D3, D4, D5, D6, D7, D8, D9, D10, D11, D12: KT-0805Y; LED0805-R-RD
J1: USB4105-GF-A; TYPE-C-SMD_SBC-160S1A-20-S412
J2: SSD1306_I2C_MODULE_DNP; PinHeader_1x04_P2.54mm_Vertical; not fitted
JFB1: AFC07-S24ECA-00; FPC-SMD_AFC07-S24ECA-00
R1, R2, R3, R4, R5, R6, R7, R8, R9, R10: 1k 1%; R_C_0603_1608Metric
R11, R12: 5.1k 1%; R_C_0603_1608Metric
R13: 3.9k 1% current limit; R_C_0603_1608Metric
R14: 15k 1% defined pulldown; R_C_0603_1608Metric
R15: 1M 1%; R_C_0603_1608Metric
R16: 35.7k 1%; R_C_0603_1608Metric
R17, R18: 10k 1%; R_C_0603_1608Metric
R19: 100k 1%; R_C_0603_1608Metric
SW1: EVPBB4A9B000 SERVICE; KEY-SMD_L2.6-W1.6-P0.75-LS3.0
SW2: EVPBB4A9B000 RESET; KEY-SMD_L2.6-W1.6-P0.75-LS3.0
U1: LTC3212EDDB#TRPBF; DFN-12-1EP_2x3mm_P0.45mm

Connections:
CH_LED_1: D3.2 (K), JFB1.10 (CH_LED_1)
CH_LED_1_A: D3.1 (A), R1.2
CH_LED_2: D4.2 (K), JFB1.11 (CH_LED_2)
CH_LED_2_A: D4.1 (A), R2.2
CH_LED_3: D5.2 (K), JFB1.12 (CH_LED_3)
CH_LED_3_A: D5.1 (A), R3.2
CH_LED_4: D6.2 (K), JFB1.13 (CH_LED_4)
CH_LED_4_A: D6.1 (A), R4.2
CH_LED_5: D7.2 (K), JFB1.14 (CH_LED_5)
CH_LED_5_A: D7.1 (A), R5.2
CH_LED_6: D8.2 (K), JFB1.15 (CH_LED_6)
CH_LED_6_A: D8.1 (A), R6.2
CH_LED_7: D9.2 (K), JFB1.16 (CH_LED_7)
CH_LED_7_A: D9.1 (A), R7.2
CH_LED_8: D10.2 (K), JFB1.17 (CH_LED_8)
CH_LED_8_A: D10.1 (A), R8.2
CH_LED_9: D11.2 (K), JFB1.18 (CH_LED_9)
CH_LED_9_A: D11.1 (A), R9.2
CH_LED_10: D12.2 (K), JFB1.19 (CH_LED_10)
CH_LED_10_A: D12.1 (A), R10.2
FB_3V3_OR_IO: C3.1, J2.2 (VCC), JFB1.2 (FB_3V3_OR_IO), R1.1, R2.1, R3.1, R4.1, R5.1, R6.1, R7.1, R8.1, R9.1, R10.1, R17.1, R18.1, U1.4 (ISETB), U1.5 (ISETR), U1.12 (VIN)
GND: C1.2, C2.2, C3.2, C5.2, C6.2, C7.2, D1.2 (GND), J1.A1 (GND), J1.A12 (GND), J1.B1 (GND), J1.B12 (GND), J2.1 (GND), JFB1.1 (GND), JFB1.3 (GND), JFB1.25 (SHIELD_A), JFB1.26 (SHIELD_B), R11.2, R12.2, R14.2, R15.2, R16.2, R19.2, SW1.B, SW1.B1, SW2.B, SW2.B1, U1.10 (GND), U1.13 (EP)
OLED_RST_OR_INT_DNP: JFB1.24 (OLED_RST_OR_INT_DNP), R19.1
OLED_SCL: J2.3 (SCL), JFB1.22 (OLED_SCL)
OLED_SDA: J2.4 (SDA), JFB1.23 (OLED_SDA)
RESET_BTN: C7.1, JFB1.21 (RESET_BTN), R18.2, SW2.A, SW2.A1
RGB_B_K: D2.4 (BLUE_K), U1.9 (LEDB)
RGB_CM: C4.2, U1.11 (CM)
RGB_CP: C4.1, U1.1 (CP)
RGB_G_K: D2.3 (GREEN_K), U1.7 (LEDG)
RGB_ISETG: R16.1, U1.6 (ISETG)
RGB_LED_ANODE: C5.1, D2.1 (COMMON_ANODE), U1.2 (CPO)
RGB_R_K: D2.2 (RED_K), U1.8 (LEDR)
SERVICE_BTN: C6.1, JFB1.20 (SERVICE_BTN), R17.2, SW1.A, SW1.A1
STATUS_RGB_DATA: JFB1.9 (STATUS_RGB_DATA), U1.3 (LEDEN)
USB_CC1: J1.A5 (CC1), JFB1.6 (USB_CC1), R11.1
USB_CC2: J1.B5 (CC2), JFB1.7 (USB_CC2), R12.1
USB_D_N: D1.4 (I_O2_OUT), JFB1.5 (USB_D_N)
USB_D_N_CONN: D1.3 (I_O2_IN), J1.A7 (D-), J1.B7 (D-)
USB_D_P: D1.6 (I_O1_OUT), JFB1.4 (USB_D_P)
USB_D_P_CONN: D1.1 (I_O1_IN), J1.A6 (D+), J1.B6 (D+)
USB_SHIELD: C2.1, J1.1 (SHIELD1), J1.2 (SHIELD2), J1.3 (SHIELD3), J1.4 (SHIELD4), R15.1
USB_VBUS: D1.5 (VBUS), J1.A4 (VBUS), J1.A9 (VBUS), J1.B4 (VBUS), J1.B9 (VBUS), R13.1
USB_VBUS_DETECT_RAW: C1.1, JFB1.8 (USB_VBUS_DETECT_RAW), R13.2, R14.1

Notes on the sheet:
FB-100 reviewed value-bearing Rev.1 capture. USB-C is USB2 device-only with two 5.1k Rd resistors, USBLC6-2SC6 flow-through ESD, current-limited VBUS detect, and no connection from USB VBUS to FB_3V3_OR_IO. LTC3212 converts the approved STATUS_RGB_DATA single wire into three regulated cathode curre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

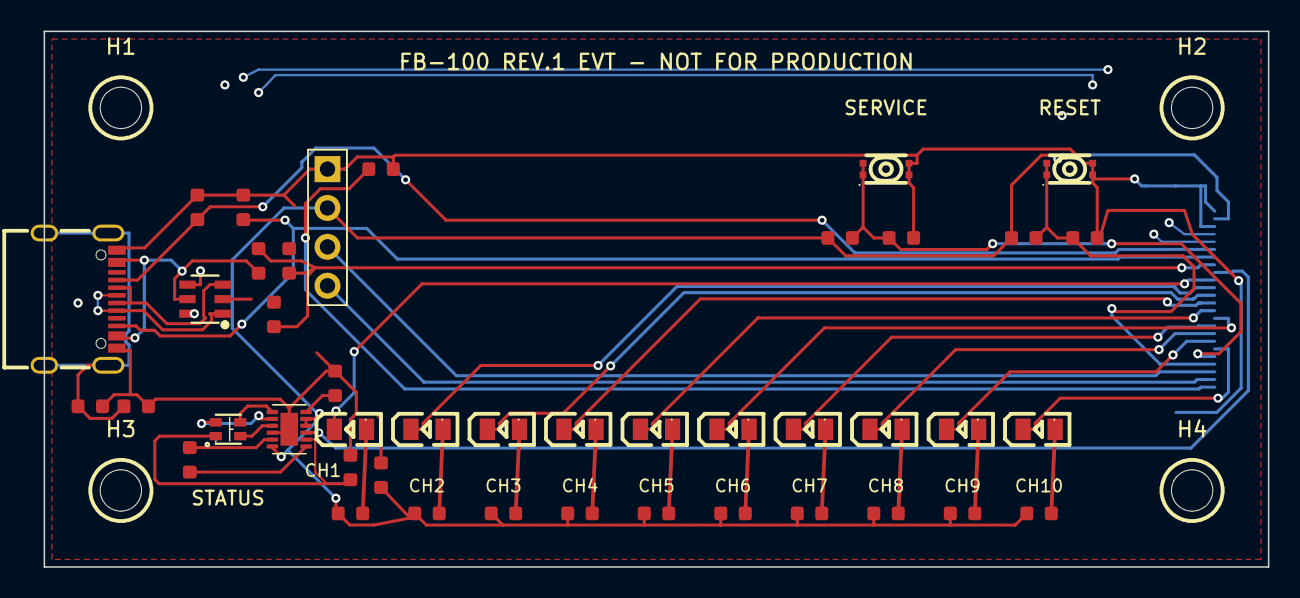
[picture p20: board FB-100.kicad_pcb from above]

Board: 4 copper layers, 80.0 x 35.0 mm, 48 parts (1 on the bottom side), 44 nets.

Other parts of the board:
H1, H2, H3, H4: M2.5 NPTH; MountingHole_2.7mm_M2.5

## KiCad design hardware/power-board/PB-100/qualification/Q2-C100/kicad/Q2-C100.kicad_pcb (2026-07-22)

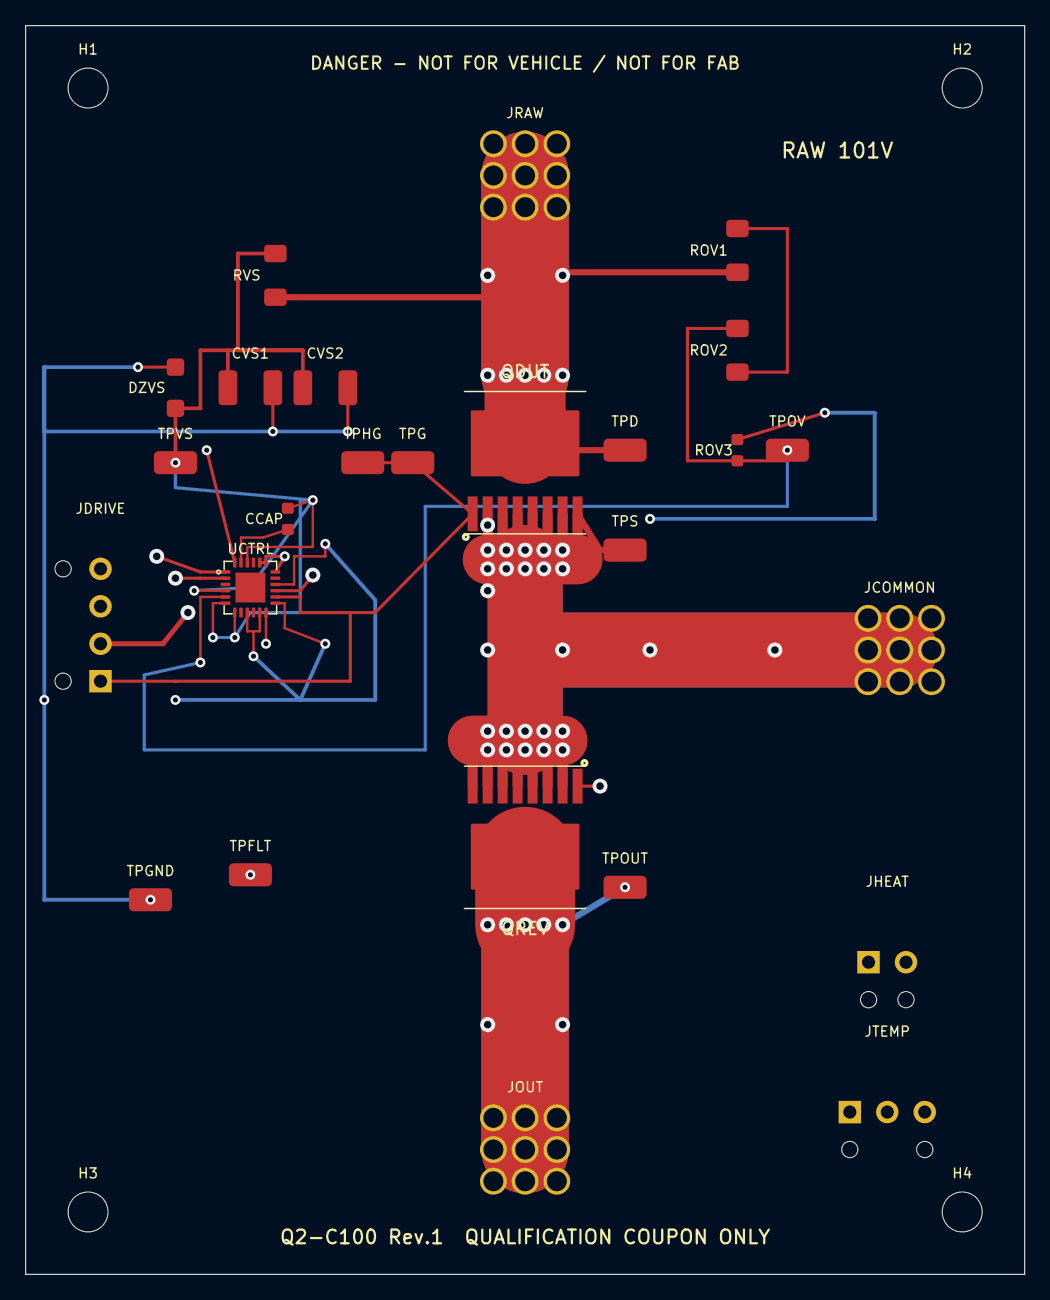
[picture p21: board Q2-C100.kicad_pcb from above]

Board: 4 copper layers, 80.0 x 100.0 mm, 30 parts (0 on the bottom side), 11 nets.

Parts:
CCAP: CGA3E2X7R1H104K080AE 100nF 50V X7R; R_C_0603_1608Metric
CVS1, CVS2: CGA6N3X7R2A225M230AE 2.2uF 100V X7R; C_1210_3225Metric
DZVS: BZT52H-B56-Q 56V; SOD123F
H1, H2, H3, H4: M3 NPTH; MountingHole_M3_NPTH
JCOMMON: 786202073 REDCUBE M3 130A COMMON; REDCUBE_786202073_3x3_P2.54
JDRIVE: 436500428 MICRO-FIT 4POS DRIVER; MicroFit_43650_0428_Vertical_R90
JHEAT: 436500228 MICRO-FIT 2POS HEATER; MicroFit_43650_0228_Vertical
JOUT: 786202073 REDCUBE M3 130A OUT; REDCUBE_786202073_3x3_P2.54
JRAW: 786202073 REDCUBE M3 130A RAW; REDCUBE_786202073_3x3_P2.54
JTEMP: 436500328 MICRO-FIT 3POS TEMP; MicroFit_43650_0328_Vertical
QDUT: IAUTN15S6N025ATMA1; PG-HSOF-8-1_TOLL_Infineon
QREV: IAUT300N08S5N012ATMA2; PG-HSOF-8-1_TOLL_Infineon
ROV1, ROV2: CRCW120642K2FKEAHP 42.2k 1%; R_1206_3216Metric
ROV3: CRCW06031K00FKEAHP 1.00k 1%; R_C_0603_1608Metric
RVS: CRCW120610K0FKEAHP 10.0k 1%; R_1206_3216Metric
TPD: S1751-46R QDUT_DRAIN_KELVIN; Harwin_S1751-46R
TPFLT: S1751-46R FAULT_PROBE; Harwin_S1751-46R
TPG: S1751-46R QDUT_GATE_KELVIN; Harwin_S1751-46R
TPGND: S1751-46R PROBE_GND; Harwin_S1751-46R
TPHG: S1751-46R UCTRL_HGATE_PROBE; Harwin_S1751-46R
TPOUT: S1751-46R SYSTEM_OUT_PROBE; Harwin_S1751-46R
TPOV: S1751-46R OV_TRIGGER_PROBE; Harwin_S1751-46R
TPS: S1751-46R QDUT_SOURCE_KELVIN; Harwin_S1751-46R
TPVS: S1751-46R CTRL_VS_PROBE; Harwin_S1751-46R
UCTRL: LM74930QRGERQ1; VQFN-24_RGE_4x4mm_P0.5mm_EP2.4mm

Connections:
COMMON_SOURCE: JCOMMON.1 (POWER), JDRIVE.2 (SOURCE_K), QDUT.2 (S), QDUT.3 (S), QDUT.4 (S), QDUT.5 (S), QDUT.6 (S), QDUT.7 (S), QDUT.8 (S), QREV.2 (S), QREV.3 (S), QREV.4 (S), QREV.5 (S), QREV.6 (S), QREV.7 (S), QREV.8 (S), TPS.1 (TP), UCTRL.2 (A), UCTRL.15 (OUT)
CTRL_CAP: CCAP.1, UCTRL.23 (CAP)
CTRL_FLT_N: TPFLT.1 (TP), UCTRL.12 (FLT)
CTRL_OV: ROV2.2, ROV3.1, TPOV.1 (TP), UCTRL.5 (OV)
CTRL_VS: CCAP.2, CVS1.1, CVS2.1, DZVS.1 (K), RVS.2, TPVS.1 (TP), UCTRL.4 (UVLO), UCTRL.6 (EN), UCTRL.7 (MODE), UCTRL.22 (VS)
GND: CVS1.2, CVS2.2, DZVS.2 (A), ROV3.2, TPGND.1 (TP), UCTRL.9 (TMR), UCTRL.11 (ILIM), UCTRL.13 (GND), UCTRL.16 (OVCLAMP)
OV_MID: ROV1.2, ROV2.1
Q2_HGATE: JDRIVE.1 (GATE), QDUT.1 (G), TPG.1 (TP), TPHG.1 (TP), UCTRL.14 (HGATE)
QREV_DGATE: QREV.1 (G), UCTRL.1 (DGATE)
RAW_101V: JRAW.1 (POWER), QDUT.Tab (D), ROV1.1, RVS.1, TPD.1 (TP)
SYSTEM_OUT: JOUT.1 (POWER), QREV.Tab (D), TPOUT.1 (TP), UCTRL.18 (ISCP), UCTRL.19 (CS-), UCTRL.20 (CS+), UCTRL.24 (C)

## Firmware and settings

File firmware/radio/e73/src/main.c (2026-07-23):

#include <errno.h>
#include <zephyr/bluetooth/bluetooth.h>
#include <zephyr/bluetooth/conn.h>
#include <zephyr/kernel.h>
#include <zephyr/logging/log.h>

#include "ble_uart_bridge.h"
#include "telemetry_stub.h"
#include "update_state.h"

LOG_MODULE_REGISTER(svc_e73, LOG_LEVEL_INF);

static svc_e73_telemetry_stub_t telemetry;
static svc_update_transfer_t update_transfer;

static void connected(struct bt_conn *connection, uint8_t error)
{
    if (error != 0U) {
        LOG_WRN("BLE connection failed: %u", error);
        return;
    }

    const int security_error = bt_conn_set_security(connection, BT_SECURITY_L2);
    if (security_error != 0 && security_error != -EALREADY) {
        LOG_WRN("BLE security request failed: %d", security_error);
    }
}

static void disconnected(struct bt_conn *connection, uint8_t reason)
{
    (void)connection;
    LOG_INF("BLE disconnected: %u", reason);
    if (update_transfer.state == SVC_UPDATE_RECEIVING) {
        (void)svc_update_interrupt(&update_transfer);
    }
}

BT_CONN_CB_DEFINE(connection_callbacks) = {
    .connected = connected,
    .disconnected = disconnected
};

int main(void)
{
    svc_e73_telemetry_stub_init(&telemetry);
    svc_update_transfer_init(&update_transfer);

    const int uart_error = svc_e73_uart_bridge_init();
    if (uart_error != 0) {
        LOG_WRN("UART bridge unavailable: %d", uart_error);
    }

    const int bluetooth_error = bt_enable(NULL);
    if (bluetooth_error != 0) {
        LOG_ERR("Bluetooth initialization failed: %d", bluetooth_error);
        return bluetooth_error;
    }

    const int advertising_error = bt_le_adv_start(
        BT_LE_ADV_CONN_FAST_1,
        NULL,
        0,
        NULL,
        0);
    if (advertising_error != 0) {
        LOG_ERR("Advertising failed: %d", advertising_error);
        return advertising_error;
    }

    LOG_INF("SVC E73 scaffold ready; telemetry remains unavailable until UART data");
    for (;;) {
        k_sleep(K_SECONDS(1));
    }
    return 0;
}

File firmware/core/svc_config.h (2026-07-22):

#pragma once

#include <stdbool.h>
#include <stdint.h>

#include "svc_types.h"

#define SVC_OUTPUT_COUNT 10U
#define SVC_DEFAULT_TOTAL_CURRENT_LIMIT_MA 40000U
#define SVC_DEFAULT_BATTERY_WARN_MV 12000U
#define SVC_DEFAULT_BATTERY_CUTOFF_MV 11800U
#define SVC_DEFAULT_BATTERY_RECOVERY_MV 12400U
#define SVC_DEFAULT_BATTERY_SHUTDOWN_DELAY_S 30U
#define SVC_THERMAL_ZONE_COUNT 3U
#define SVC_DEFAULT_THERMAL_WARN_C 85
#define SVC_DEFAULT_THERMAL_CUTOFF_C 105
#define SVC_DEFAULT_THERMAL_RECOVERY_C 75
#define SVC_DEFAULT_TOTAL_CURRENT_SHUNT_UOHM 500U
#define SVC_DEFAULT_TOTAL_CURRENT_MONITOR_RANGE_UV 40960U
#define SVC_DEFAULT_TOTAL_CURRENT_ZERO_OFFSET_MA 0
#define SVC_DEFAULT_TOTAL_CURRENT_GAIN_PPM 1000000U
#define SVC_DEFAULT_TELEMETRY_STALE_TIMEOUT_MS 1000U
#define SVC_DEFAULT_TOTAL_CURRENT_PLAUSIBLE_MAX_MA 60000U
#define SVC_DEFAULT_OUTPUT_CURRENT_ZERO_OFFSET_MA 0
#define SVC_DEFAULT_OUTPUT_CURRENT_GAIN_PPM 1000000U
#define SVC_DEFAULT_OUTPUT_CURRENT_STALE_TIMEOUT_MS 1000U
#define SVC_DEFAULT_OUT1_CURRENT_RANGE_MA 20000U
#define SVC_DEFAULT_OUT2_CURRENT_RANGE_MA 30000U
#define SVC_DEFAULT_OUT3_CURRENT_RANGE_MA 15000U
#define SVC_DEFAULT_OUT4_CURRENT_RANGE_MA 15000U
#define SVC_DEFAULT_OUT5_CURRENT_RANGE_MA 8000U
#define SVC_DEFAULT_OUT6_CURRENT_RANGE_MA 15000U
#define SVC_DEFAULT_OUT7_CURRENT_RANGE_MA 15000U
#define SVC_DEFAULT_OUT8_CURRENT_RANGE_MA 8000U
#define SVC_DEFAULT_OUT9_CURRENT_RANGE_MA 8000U
#define SVC_DEFAULT_OUT10_CURRENT_RANGE_MA 15000U
#define SVC_DEFAULT_THERMAL_NTC_NOMINAL_OHM 10000U
#define SVC_DEFAULT_THERMAL_NTC_BETA_K 3435U
#define SVC_DEFAULT_THERMAL_PULLUP_OHM 4700U
#define SVC_DEFAULT_THERMAL_ADC_SERIES_OHM 1000U
#define SVC_DEFAULT_THERMAL_FILTER_NF 10U
#define SVC_DEFAULT_THERMAL_STALE_TIMEOUT_MS 1000U
#define SVC_DEFAULT_THERMAL_PLAUSIBLE_MIN_C -40
#define SVC_DEFAULT_THERMAL_PLAUSIBLE_MAX_C 150
#define SVC_DEFAULT_FOG_DEBOUNCE_MS 50U
#define SVC_DEFAULT_FOG_STUCK_TIMEOUT_MS 30000U
#define SVC_DEFAULT_FOG_CHANNEL_DELAY_MS 150U

typedef enum {
    SVC_OUTPUT_OUT1 = 0,
    SVC_OUTPUT_OUT2,
    SVC_OUTPUT_OUT3,
    SVC_OUTPUT_OUT4,
    SVC_OUTPUT_OUT5,
    SVC_OUTPUT_OUT6,
    SVC_OUTPUT_OUT7,
    SVC_OUTPUT_OUT8,
    SVC_OUTPUT_OUT9,
    SVC_OUTPUT_OUT10
} svc_output_id_t;

typedef enum {
    SVC_PRIORITY_A = 0,
    SVC_PRIORITY_B,
    SVC_PRIORITY_C
} svc_load_priority_t;

typedef enum {
    SVC_THERMAL_ZONE_PCB = 0,
    SVC_THERMAL_ZONE_PWR_A,
    SVC_THERMAL_ZONE_PWR_B
} svc_thermal_zone_t;

typedef struct {
    svc_output_id_t id;
    output_role_t role;
    uint16_t fuse_limit_a;
    uint16_t current_limit_ma;
    bool pwm_allowed;
    svc_load_priority_t priority;
} svc_output_config_t;

typedef struct {
    uint32_t total_current_limit_ma;
    svc_load_priority_t shed_order[3];
} svc_power_budget_config_t;

typedef struct {
    uint16_t warn_mv;
    uint16_t cutoff_mv;
    uint16_t recovery_mv;
    uint16_t shutdown_delay_s;
} svc_battery_config_t;

typedef struct {
    int16_t warn_c;
    int16_t cutoff_c;
    int16_t recovery_c;
} svc_thermal_zone_config_t;

typedef struct {
    uint16_t shunt_microohm;
    uint32_t monitor_range_uv;
    int32_t zero_offset_ma;
    uint32_t gain_ppm;
    uint32_t stale_timeout_ms;
    uint32_t plausible_max_ma;
} svc_total_current_telemetry_config_t;

typedef struct {
    uint32_t range_ma;
    int32_t zero_offset_ma;
    uint32_t gain_ppm;
    uint32_t stale_timeout_ms;
    uint32_t plausible_max_ma;
} svc_output_current_telemetry_config_t;

typedef struct {
    uint32_t ntc_nominal_ohm;
    uint16_t ntc_beta_k;
    uint32_t pullup_ohm;
    uint32_t adc_series_ohm;
    uint16_t filter_nf;
    uint32_t stale_timeout_ms;
    int16_t plausible_min_c;
    int16_t plausible_max_c;
} svc_thermal_telemetry_config_t;

typedef struct {
    svc_total_current_telemetry_config_t total_current;
    svc_output_current_telemetry_config_t output_current[SVC_OUTPUT_COUNT];
    svc_thermal_telemetry_config_t thermal[SVC_THERMAL_ZONE_COUNT];
} svc_telemetry_config_t;

typedef struct {
    enum {
        SVC_MANUAL_INPUT_MOMENTARY_TOGGLE = 0,
        SVC_MANUAL_INPUT_MAINTAINED
    } behavior;
    bool active_low;
    uint32_t debounce_ms;
    uint32_t stuck_timeout_ms;
    uint32_t channel_delay_ms;
    output_role_t roles[2];
} svc_manual_fog_input_config_t;

typedef struct {
    svc_manual_fog_input_config_t pair_a;
    svc_manual_fog_input_config_t pair_b;
    bool restore_on_boot;
    bool output_manager_authority;
} svc_manual_fog_config_t;

typedef struct {
    svc_battery_config_t battery;
    svc_thermal_zone_config_t thermal[SVC_THERMAL_ZONE_COUNT];
    svc_power_budget_config_t power_budget;
    svc_telemetry_config_t telemetry;
    svc_manual_fog_config_t manual_fog;
    svc_output_config_t outputs[SVC_OUTPUT_COUNT];
} svc_device_config_t;

extern const svc_device_config_t svc_default_config;

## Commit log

2026-06-30 Initial SVC platform structure
    [SVC_Platform_BOM_Draft.xlsx, factory_bom_draft.csv, garage_bom_draft.csv]
2026-06-30 docs: select initial component families
    [factory_bom_draft.csv]
2026-06-30 docs: define pb100 current budget
    [garage_bom_draft.csv]
2026-06-30 hardware: add pb100 schematic input tables
    [PB-100-b2b-pin-budget.csv, PB-100-output-channel-matrix.csv]
2026-06-30 hardware: select pb100 power path candidates
    [PB-100-output-channel-matrix.csv, PB-100-power-path-candidates.csv, factory_bom_draft.csv]
2026-06-30 hardware: add pb100 preliminary validation
    [PB-100-power-path-candidates.csv, PB-100-protection-validation.csv, PB-100-thermal-estimates.csv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]
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2026-06-30 hardware: use external controllers for low-current outputs
    [PB-100-output-channel-matrix.csv, PB-100-power-path-candidates.csv, PB-100-protection-validation.csv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]
2026-06-30 hardware: add pb100 b2b pin map
    [PB-100-b2b-pin-map.csv]
2026-06-30 hardware: define pb100 input reverse fet strategy
    [PB-100-power-path-candidates.csv, PB-100-protection-validation.csv, PB-100-thermal-estimates.csv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]
2026-06-30 hardware: define pb100 out2 soa envelope
    [PB-100-out2-soa-envelope.csv, PB-100-power-path-candidates.csv, factory_bom_draft.csv]
2026-06-30 hardware: define pb100 logic power rails
    [PB-100-logic-power-budget.csv, PB-100-power-path-candidates.csv, PB-100-protection-validation.csv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]
2026-06-30 hardware: define pb100 current telemetry
    [PB-100-current-telemetry-map.csv, factory_bom_draft.csv]
2026-06-30 hardware: define pb100 thermal telemetry
    [PB-100-thermal-telemetry-map.csv, factory_bom_draft.csv]
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2026-06-30 hardware: add pb100 kicad preparation plan
    [PB-100-kicad-footprint-plan.csv]
2026-06-30 hardware: add pb100 schematic capture contract
    [PB-100-schematic-instance-plan.csv]
2026-06-30 hardware: add pb100 kicad schematic scaffold
    [PB-100.kicad_sch]
2026-06-30 hardware: add pb100 kicad child sheet placeholders
    [b2b-interface.kicad_sch, can1-safety.kicad_sch, input-protection.kicad_sch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]
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2026-06-30 hardware: define pb100 garage connector plan
    [PB-100-garage-connector-fuse-plan.csv, garage_bom_draft.csv]
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2026-06-30 hardware: add pb100 symbol mpn readiness gate
    [PB-100-symbol-mpn-readiness.csv]
2026-06-30 hardware: add pb100 symbol capture worklist
    [PB-100-symbol-capture-worklist.csv]
2026-06-30 hardware: add initial pb100 concrete symbols
    [PB-100-symbol-capture-worklist.csv]
2026-06-30 hardware: validate pb100 symbol pin evidence
    [PB-100-symbol-pin-evidence.csv]
2026-06-30 hardware: add pb100 passive class symbols
    [PB-100-symbol-capture-worklist.csv, PB-100-symbol-pin-evidence.csv]
2026-06-30 hardware: add pb100 mosfet preliminary symbols
    [PB-100-symbol-capture-worklist.csv, PB-100-symbol-pin-evidence.csv]
2026-06-30 hardware: add pb100 jpb1 preliminary symbol
    [PB-100-symbol-capture-worklist.csv]
2026-06-30 hardware: add pb100 output fuse symbol
    [PB-100-symbol-capture-worklist.csv, PB-100-symbol-mpn-readiness.csv, PB-100-symbol-pin-evidence.csv]
2026-06-30 hardware: map pb100 instances to symbols
    [PB-100-schematic-instance-symbol-map.csv, PB-100-symbol-capture-worklist.csv, PB-100-symbol-mpn-readiness.csv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]
2026-06-30 hardware: map pb100 instances to sheets
    [PB-100-schematic-sheet-reference-map.csv]
2026-06-30 hardware: add pb100 kicad sheet manifest
    [PB-100-kicad-sheet-manifest.csv]
2026-06-30 hardware: add pb100 schematic net domain plan
    [PB-100-schematic-net-domain-plan.csv]
2026-06-30 production: map pb100 symbols to bom
    [factory_bom_draft.csv, garage_bom_draft.csv, pb100_symbol_bom_map.csv]
2026-06-30 hardware: add pb100 schematic readiness contracts
    [PB-100-input-protection-pin-contract.csv, PB-100-logic-power-design-placeholders.csv, PB-100-output-channel-pin-contract.csv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]
2026-06-30 hardware: add pb100 output controller template
    [PB-100-output-controller-pin-template.csv, PB-100-schematic-net-domain-plan.csv, PB-100-schematic-readiness-dashboard.csv]
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2026-07-09 config: tighten rule validation
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2026-07-10 hardware: tighten pb100 can1 disable contract
    [PB-100-can1-safety-verification.csv, PB-100-schematic-capture-work-queue.csv, PB-100-schematic-freeze-gap-register.csv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]
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2026-07-10 hardware: trace pb100 input reverse package
    [PB-100-input-reverse-package-trace.csv, PB-100-review-release-manifest.csv, PB-100-schematic-freeze-gap-register.csv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]
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2026-07-10 hardware: add pb100 b2b resource binding
    [PB-100-b2b-interface-trace.csv, PB-100-b2b-lb100-resource-binding.csv, PB-100-kicad-sheet-manifest.csv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]
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2026-07-10 hardware: add pb100 input reverse freeze review
    [PB-100-input-reverse-freeze-review.csv, PB-100-kicad-sheet-manifest.csv, PB-100-review-release-manifest.csv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]
2026-07-10 hardware: add pb100 tvs load dump freeze review
    [PB-100-kicad-sheet-manifest.csv, PB-100-review-release-manifest.csv, PB-100-schematic-capture-work-queue.csv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]
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2026-07-17 Add PB-100 CAN1 reset bench checklist
    [PB-100-board-release-blocker-register.csv, PB-100-can1-reset-bench-checklist.csv, PB-100-review-release-manifest.csv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]
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2026-07-17 Add PB-100 input reverse Q1 checklist
    [PB-100-board-release-blocker-register.csv, PB-100-input-reverse-q1-freeze-checklist.csv, PB-100-kicad-sheet-manifest.csv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]
2026-07-17 Add PB-100 TVS overshoot escape checklist
    [PB-100-board-release-blocker-register.csv, PB-100-kicad-sheet-manifest.csv, PB-100-review-release-manifest.csv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]
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2026-07-17 Add PB-100 input reverse Q1 derivation precheck
    [PB-100-board-release-blocker-register.csv, PB-100-input-reverse-q1-derivation-precheck.csv, PB-100-kicad-sheet-manifest.csv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]
2026-07-17 Add PB-100 TVS overshoot validation precheck
    [PB-100-board-release-blocker-register.csv, PB-100-kicad-sheet-manifest.csv, PB-100-review-release-manifest.csv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]
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2026-07-17 Add PB-100 input reverse Q1 closeout precheck
    [PB-100-board-release-blocker-register.csv, PB-100-input-reverse-q1-closeout-precheck.csv, PB-100-kicad-sheet-manifest.csv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]
2026-07-17 Add PB-100 TVS overshoot closeout precheck
    [PB-100-board-release-blocker-register.csv, PB-100-kicad-sheet-manifest.csv, PB-100-review-release-manifest.csv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]
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2026-07-20 Fail safe on stale current telemetry
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2026-07-20 Avoid battery elapsed conversion overflow
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2026-07-20 Add three-board footprint binding inventory
    [FB-100-footprint-binding-inventory.csv, FB-100-pcb-layout-start-checklist.csv, FB-100.kicad_sch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]
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2026-07-20 Close FB USB no back power layout model
    [FB-100-component-sourcing-precheck.csv, FB-100-footprint-binding-inventory.csv, FB-100-pcb-layout-start-checklist.csv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]
2026-07-20 Close FB local footprint binding
    [FB-100-footprint-binding-closeout.csv, FB-100-footprint-binding-inventory.csv, FB-100-pcb-layout-start-checklist.csv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]
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2026-07-20 fix(readiness): enforce cross-document consistency
    [LB-100-footprint-binding-progress.csv, LB-100-pcb-layout-start-checklist.csv, PB-100-board-print-closure-matrix.csv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]
2026-07-20 feat(hardware): close LB FB schematics and FX18 mechanics
    [FB-100-board-release-blocker-register.csv, FB-100-component-sourcing-precheck.csv, FB-100-footprint-binding-inventory.csv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]
2026-07-21 feat(pb100): close five pre-layout blockers with generated evidence
    [PB-100-assembly-readiness-trace.csv, PB-100-board-current-budget-closeout-precheck.csv, PB-100-board-current-budget-freeze-review.csv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]
2026-07-21 fix: reopen load dump and correct LB FB electricals
    [FB-100-board-release-blocker-register.csv, FB-100-component-sourcing-precheck.csv, FB-100-interface-pinout-closeout.csv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]
2026-07-21 fix: isolate BLE domain and define USB detect
    [FB-100-board-release-blocker-register.csv, FB-100-component-sourcing-precheck.csv, FB-100-interface-pinout-closeout.csv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]
2026-07-21 fix: stage PB release authorization
    [FB-100-review-release-manifest.csv, LB-100-fb-powered-off-calculation-evidence.csv, LB-100-review-release-manifest.csv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]
2026-07-21 fix(pb100): select active surge cutoff architecture
    [PB-100-assembly-readiness-trace.csv, PB-100-board-print-closure-matrix.csv, PB-100-board-release-blocker-register.csv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]
2026-07-21 Fix PBREL-007 Q2 evidence
    [PB-100-assembly-readiness-trace.csv, PB-100-board-print-closure-matrix.csv, PB-100-board-release-blocker-register.csv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]
2026-07-21 fix(pb100): correct hot-start surge SOA gate
    [PB-100-board-print-closure-matrix.csv, PB-100-board-release-blocker-register.csv, PB-100-board-release-local-evidence-closeout.csv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]
2026-07-21 fix(pb100): bound surge turnoff and protected peak
    [PB-100-board-release-blocker-register.csv, PB-100-board-release-local-evidence-closeout.csv, PB-100-input-q2-evidence.csv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]
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2026-07-21 feat(q2): strengthen coupon pre-fab evidence
    [PB-100-board-release-blocker-register.csv, PB-100-q2-empirical-qualification-readiness.csv, PB-100-staged-release-readiness.csv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]
2026-07-21 feat(q2): bind coupon fixture interfaces
    [PB-100-board-release-blocker-register.csv, PB-100-q2-empirical-qualification-readiness.csv, PB-100-staged-release-readiness.csv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]
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2026-07-22 hardware: correct fog entry and EVT layout gates
    [FB-100-fog-button-fit-review.csv, LB-100-board-release-blocker-register.csv, LB-100-component-sourcing-precheck.csv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]
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2026-07-22 feat: add E73 recovery and persistent CAN logging
    [FB-100-evt-fab-review-checklist.csv, LB-100-board-release-blocker-register.csv, LB-100-footprint-binding-progress.csv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]
2026-07-22 feat: harden LB RF layout and CAN logging
    [FB-100-evt-fab-review-checklist.csv, FB-100-review-release-manifest.csv, FB-100-routing.csv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]
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
